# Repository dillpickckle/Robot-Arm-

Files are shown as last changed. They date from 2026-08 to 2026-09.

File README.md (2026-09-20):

5-DOF Robot Arm

A robotic arm with 400mm reach and a 250g payload, designed and built from scratch.

Robot arm
Status

Hardware: Complete — CAD, STEP files, wiring diagrams, Rough firmware, and BOM are in this repo.

Specs
5 degrees of freedom + gripper
400mm reach, 250g payload
3× NEMA 17 steppers with planetary gearboxes (base 5:1, shoulder 20:1, elbow 20:1)
3× Feetech STS3215 bus servos (wrist pitch, wrist roll, gripper)
Teensy 4.1 controller, 3× TMC2209 stepper drivers
24V power system with 12V and 5V rails
Designed in Fusion 360, printed in PETG / PA6-CF / PLA

Notes on the CAD files

No screws or bolts. Mapping every fastener would have cluttered the file without adding useful information. The BOM and assembly guide list what goes where.

No electronics. The Teensy, TMC2209s, buck converters, and other PCBs aren't modeled — I couldn't find accurate CAD for them, and the manufacturers don't publish dimensioned drawings. I'll update these once I have the parts in hand to measure.

Planetary gearbox mounting points are approximate. The manufacturer doesn't specify them. Also getting updated once I can measure them myself.

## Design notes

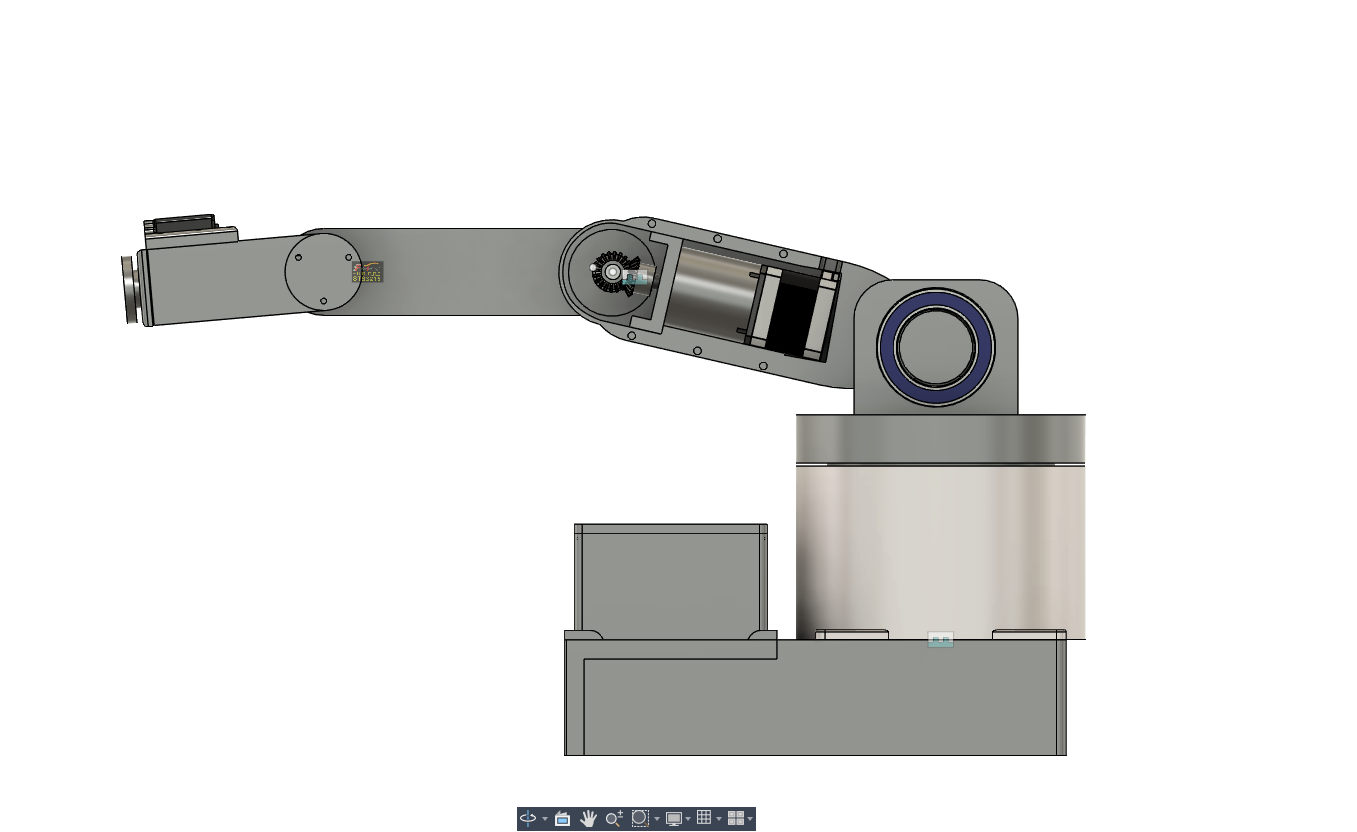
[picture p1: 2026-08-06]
Images/Screenshot 2026-08-06 085324.png

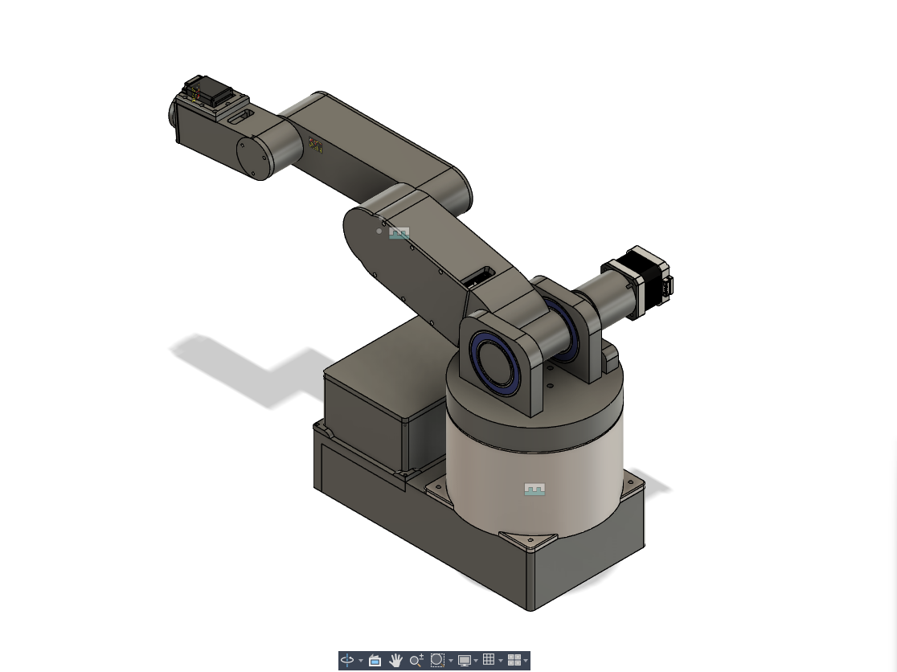
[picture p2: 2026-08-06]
Images/Screenshot 2026-08-06 085304.png

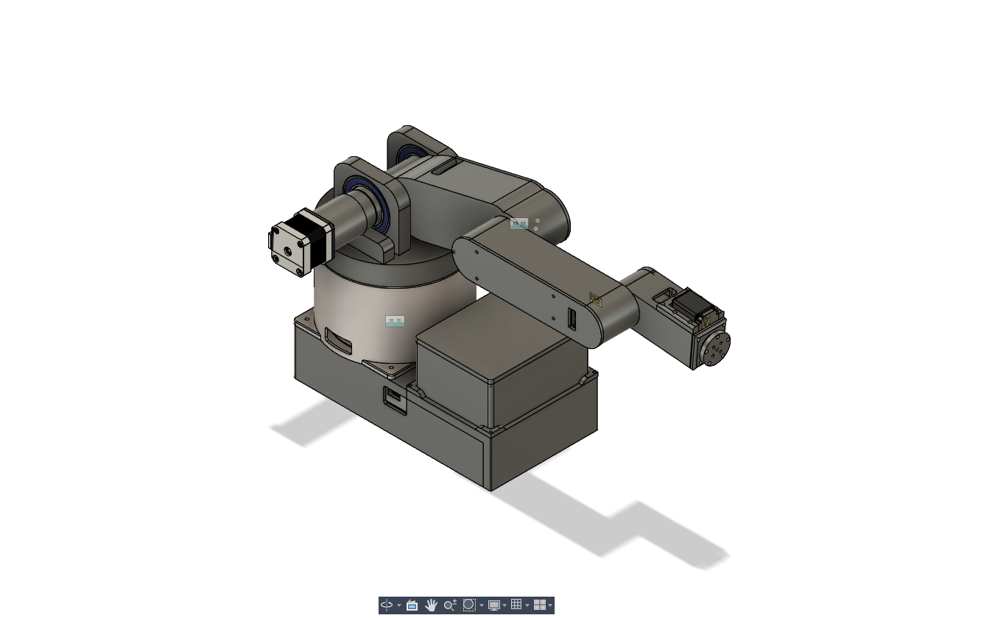
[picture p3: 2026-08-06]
Images/Screenshot 2026-08-06 085240.png

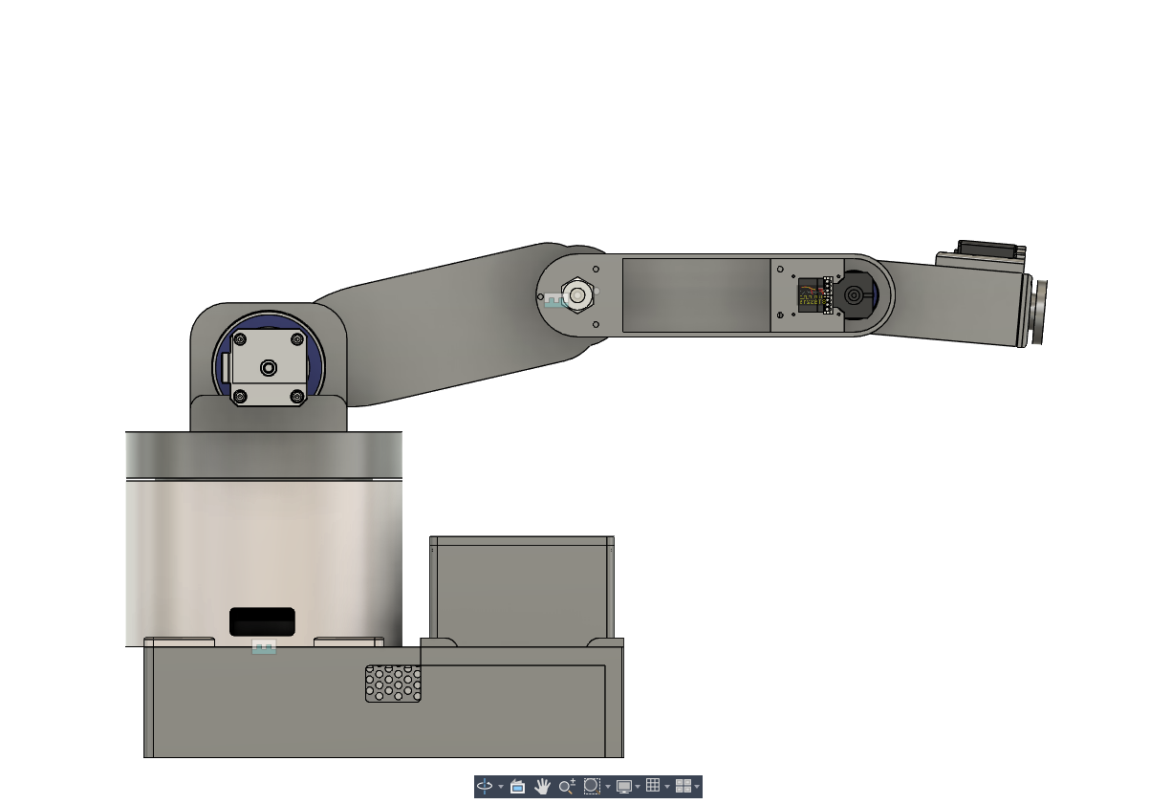
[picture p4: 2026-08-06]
Images/Screenshot 2026-08-06 085339.png

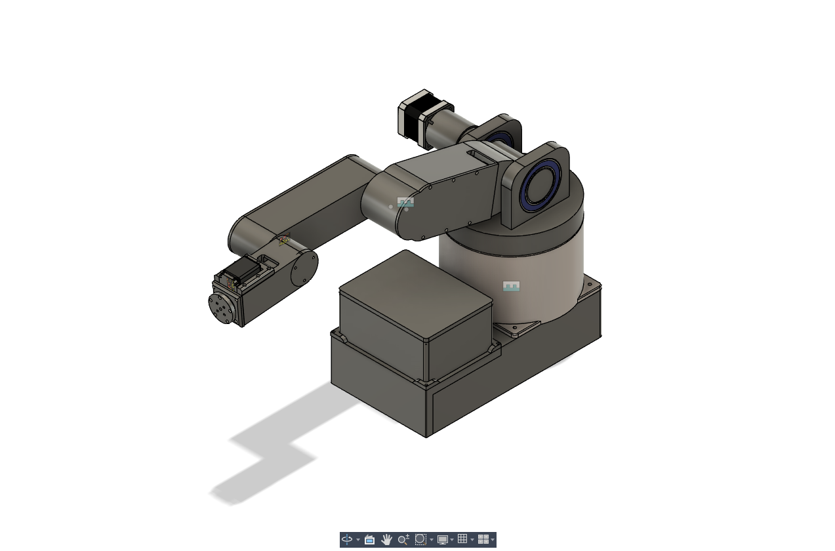
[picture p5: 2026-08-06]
Images/Screenshot 2026-08-06 085252.png

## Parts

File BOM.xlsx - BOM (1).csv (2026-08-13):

5-DOF Robot Arm - Bill of Materials
HARDWARE
Part | Qty Needed | Total Price | Source | Link
688ZZ Ball Bearing 8x16x5 | 2 | $4.73 | AliExpress | Link
6704RS Ball Bearing 20x27x4 | 2 | $1.88 | AliExpress | Link
MR52ZZ Mini Ball Bearing 2x5x2.5 | 1 | $8.59 | Amazon | Link
Thrust Bearing 90x120x4 | 1 | $8.37 | AliExpress | Link
Wheel Hex Drive Hub | 1 | $0.99 | AliExpress | Link
NEMA 17 Shaft Coupling (jaw) | 1 | $4.27 | AliExpress | Link
Spiral Bevel Gear (matched pair) | 2 | $11.85 | AliExpress | Link
Ball Bearing 6908 (40x62x12) | 2 | $9.00 | Amazon | Link
M3/M4/M5 Screw Assortment Kit | 1 | $23.00 | Amazon | Link
Heat-Set Insert Assortment Kit | 1 | $16.00 | Amazon | Link
HARDWARE SUBTOTAL |  | $88.68
MOTORS & DRIVE
Part | Qty Needed | Total Price | Source | Link
20:1 Planetary Gearbox (NEMA 17) | 1 | $26.50 | AliExpress | Link
5:1 Planetary Gearbox (NEMA 17) | 2 | $38.78 | AliExpress | Link
NEMA 17 Stepper 42N.cm | 3 | $27.27 | AliExpress | Link
STS3215 30kg Serial Bus Servo | 3 | $75.70 | AliExpress | Link
MOTORS & DRIVE SUBTOTAL |  | $168.25
ELECTRONICS
Part | Qty Needed | Total Price | Source | Link
Teensy 4.1 Microcontroller | 1 | $34.90 | Amazon | Link
TMC2209 Stepper Driver | 3 | $14.10 | AliExpress | Link
Waveshare Bus Servo Adapter (URT-1) | 1 | $17.19 | AliExpress | Link
24V PSU (200W / 8.8A) | 1 | $31.43 | AliExpress | Link
24V to 12V Buck Converter (5A) | 1 | $5.71 | AliExpress | Link
24V to 5V Buck Converter (3A) | 1 | $1.39 | AliExpress | Link
Main Power Rocker Switch | 1 | $1.61 | AliExpress | Link
Emergency Stop Button (NC) | 1 | $2.61 | AliExpress | Link
Limit Switch w/ lever | 3 | $0.99 | Aliexpress | Link
JST-XH Connector Kit + crimp tool | 1 | $30 | Amazon | Link
22 AWG Stranded Wire (multi-color) | 1 | $21 | Amazon | Link
18 AWG Wire (red/black) | 1 | $8 | Amazon | Link
Heat Shrink Tubing Assortment | 1 | $14 | Amazon | Link
Header Pin Strips (40-pin) | 1 | $8 | Amazon | Link
ELECTRONICS SUBTOTAL |  | $190.93
SHIPPING & FEES
Item |  | Total Price | Source
AliExpress Shipping |  | $30.00 | AliExpress
AliExpress Import / Customs Fees |  | $30.00 | AliExpress
Amazon Shipping |  | $0.00 | Amazon (Prime Member)
SHIPPING & FEES SUBTOTAL |  | $60.00
GRAND TOTAL |  | $507.86

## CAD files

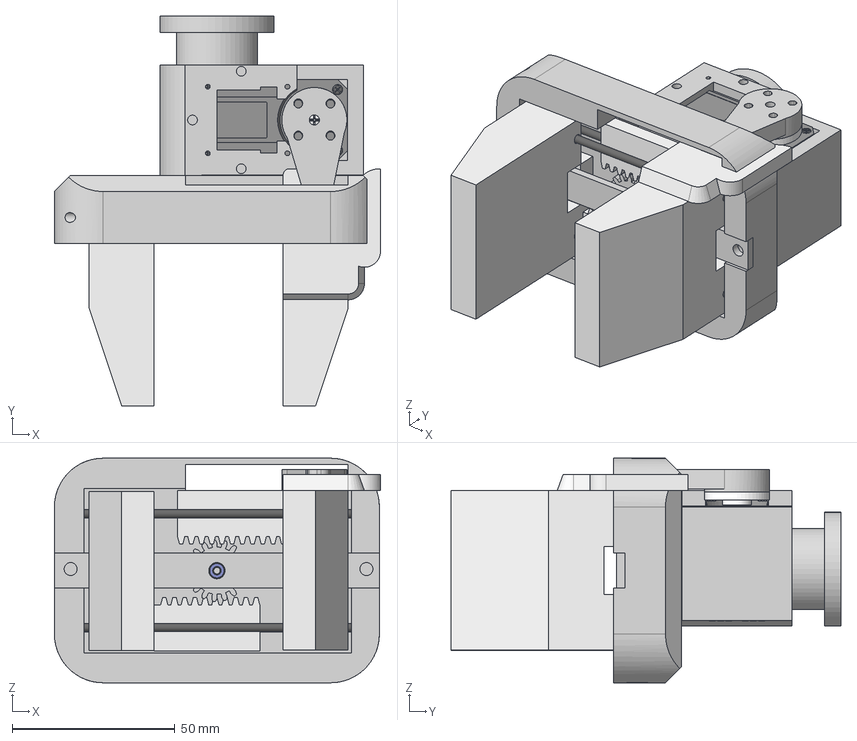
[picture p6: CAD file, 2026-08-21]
Production/Assembly Files/GripperFullAssembly.step
100.4 x 120.0 x 69.1 mm
SpurGear
vis x 2
connector F x 2
PHS JIS B 1111 - M3 x 4 - H Acier inoxydable A2 Standard
Inner ring
Covers
Outer ring
Inner ring (1)
Covers (1)
Outer ring (1)
ServoMount
Gripper2
ServoAttachment
gripper1
Main Body
BearingMount
Horizontal Rod
Horizontal ROD_1
Horizontal Rod (1)
Horizontal Rod (1) (1)

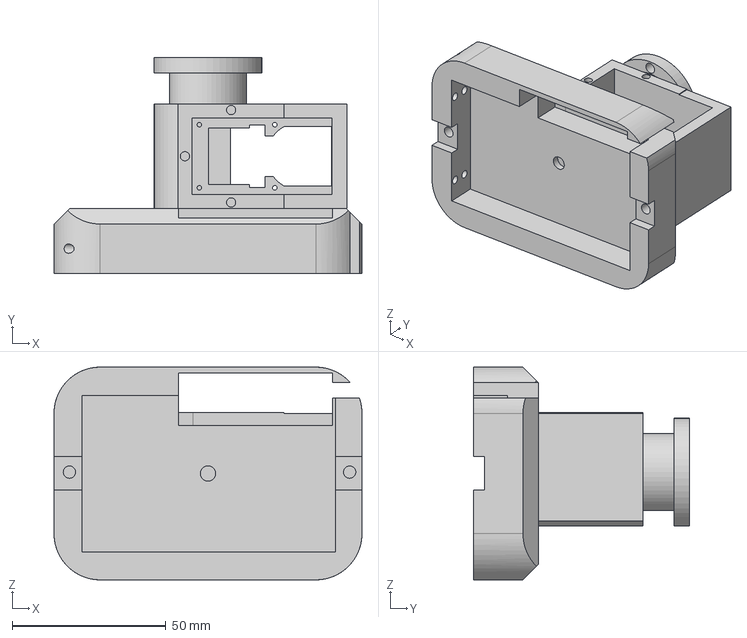
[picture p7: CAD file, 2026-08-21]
Production/Step Files/Gripper/MainBody.step
100.0 x 70.0 x 69.1 mm

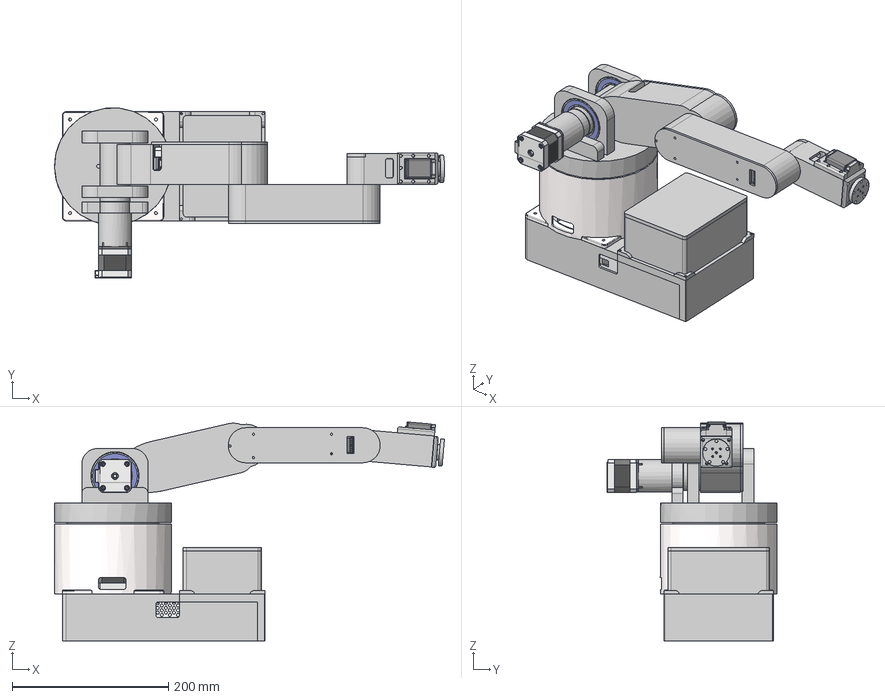
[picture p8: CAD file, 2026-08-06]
Production/Assembly Files/Fully Assembled.step
499.8 x 217.5 x 280.6 mm
Inner ring
Covers
Outer ring
rear end cap x 3
rear bearing x 3
connector x 3
shaft x 3
stator x 3
front end cap x 3
front bearing x 3
M3x10-Screw x 12
20:1 Planetary Gearbox x 3
CouplingJ1
Base
Inner ring (1)
Covers (1)
Outer ring (1)
Inner ring (2)
Covers (2)
Outer ring (2)
BevelJ32 x 2
NEMA MOUNT
ShoulderCover
vis x 4
connector F x 4
PHS JIS B 1111 - M3 x 4 - H Acier inoxydable A2 Standard x 2
ServoMountJ4
StepperMountJ5
Inner ring (3)
Covers (3)
Outer ring (3)
DriveHub
MetalBar
TopBase
Linkage1
J5BearingMount
J5Flange
Inner ring (4)
Covers (4)
Outer ring (4)
Linkage3
Linkage2
Inner ring (5)
Covers (5)
Outer ring (5)
Inner ring (6)
Covers (6)
Outer ring (6)
M3x6-Screw x 4
M3x6-Screw011
ElectronicsMainBox
SEBcover
SecondaryElectricsBox
ElectronicsMBcover
J1PlanetaryMount
J4Cover
J3/4Cover

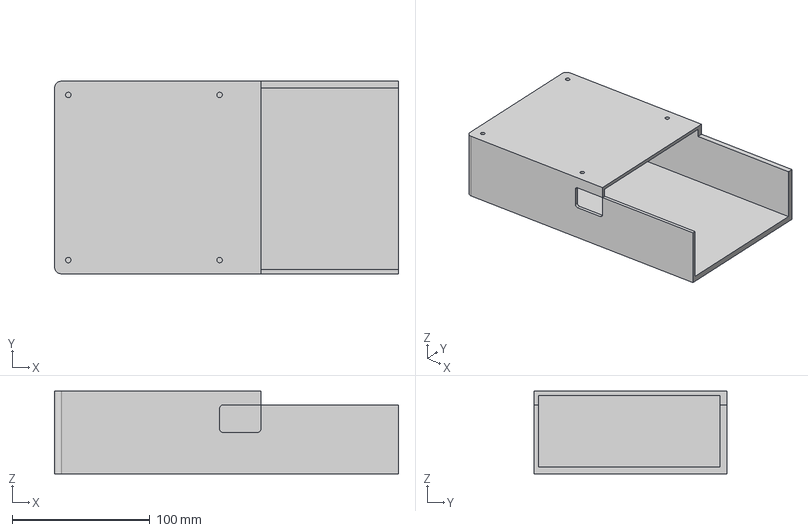
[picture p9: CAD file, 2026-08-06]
Production/Step Files/Robot Arm/ElectronicsMainBox.step
250.0 x 140.0 x 60.0 mm

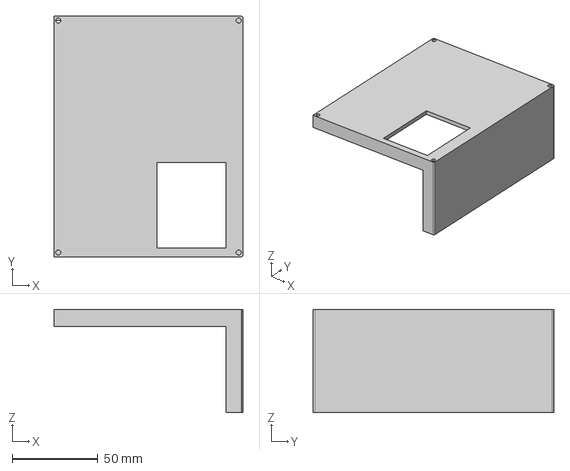
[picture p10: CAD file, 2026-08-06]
Production/Step Files/Robot Arm/ElectronicsMBcover.step
110.0 x 140.0 x 60.0 mm

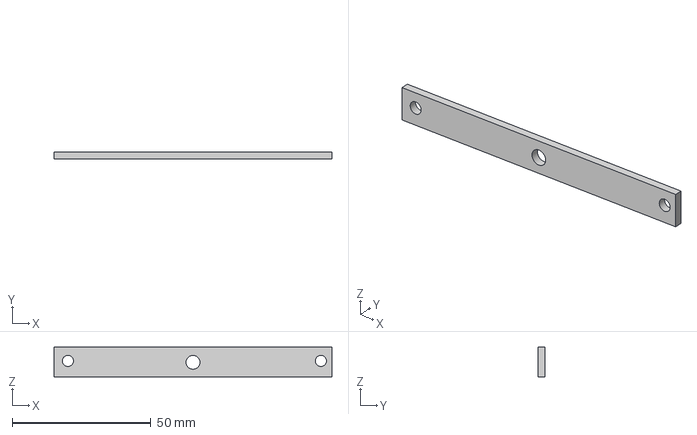
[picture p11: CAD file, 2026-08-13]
Production/Step Files/Gripper/BearingMount.step
100.0 x 2.50 x 10.8 mm

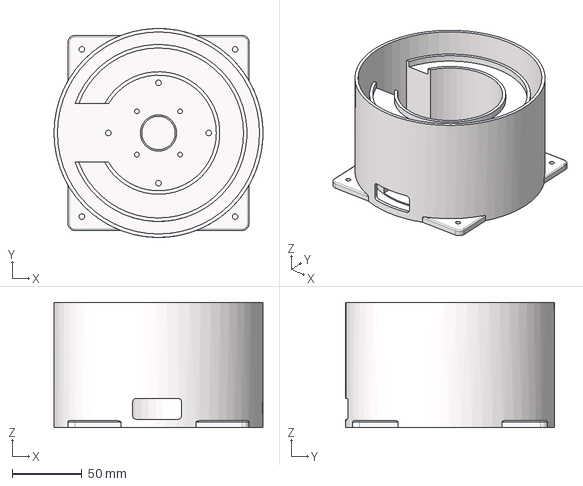
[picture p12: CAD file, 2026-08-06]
Production/Step Files/Robot Arm/Base.step
150.0 x 150.0 x 90.0 mm

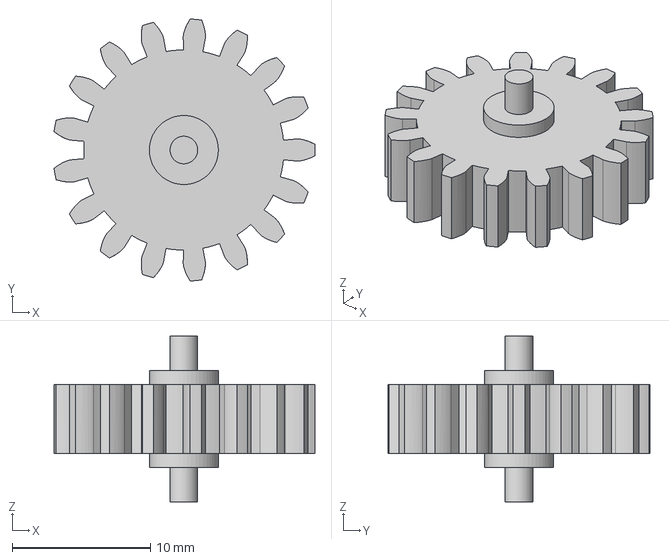
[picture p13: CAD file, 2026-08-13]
Production/Step Files/Gripper/SpurGear.step
18.9 x 19.0 x 12.0 mm

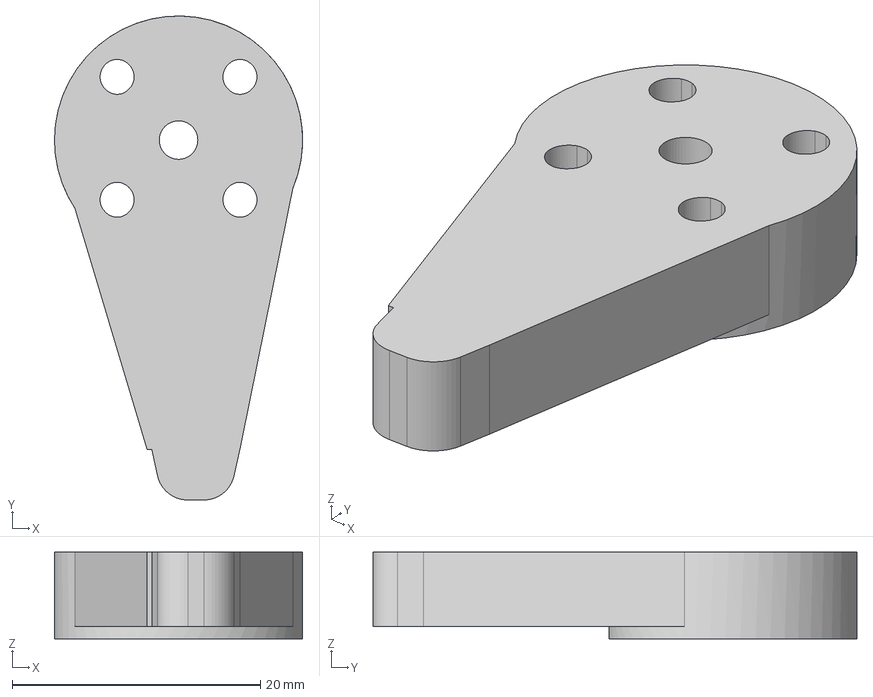
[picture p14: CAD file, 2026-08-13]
Production/Step Files/Gripper/ServoAttachment.step
20.0 x 39.0 x 7.00 mm

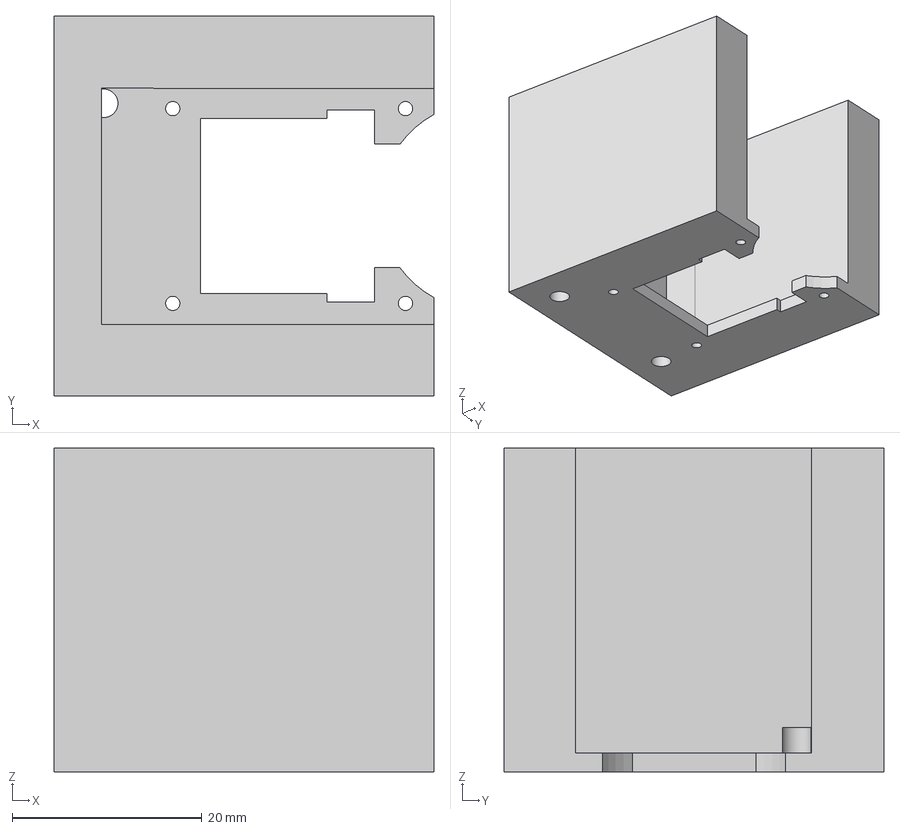
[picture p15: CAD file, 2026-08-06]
Production/Step Files/Robot Arm/ServoMountJ4.step
40.0 x 40.0 x 34.1 mm

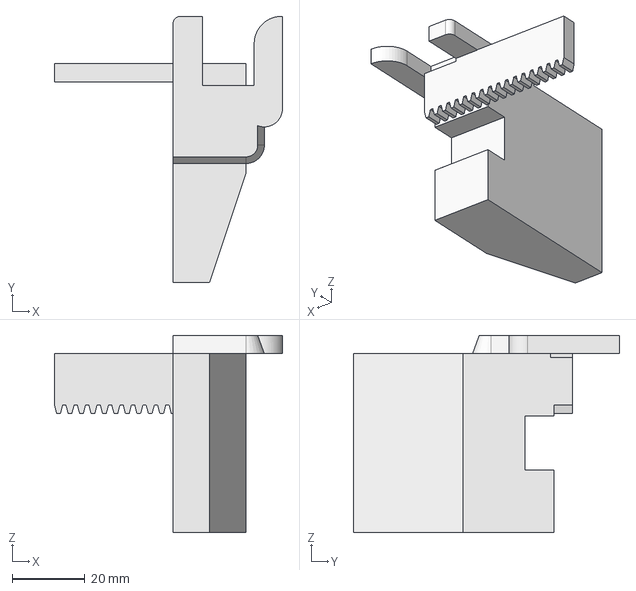
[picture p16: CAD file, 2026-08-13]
Production/Step Files/Gripper/Gripper2.step
62.5 x 73.0 x 54.0 mm

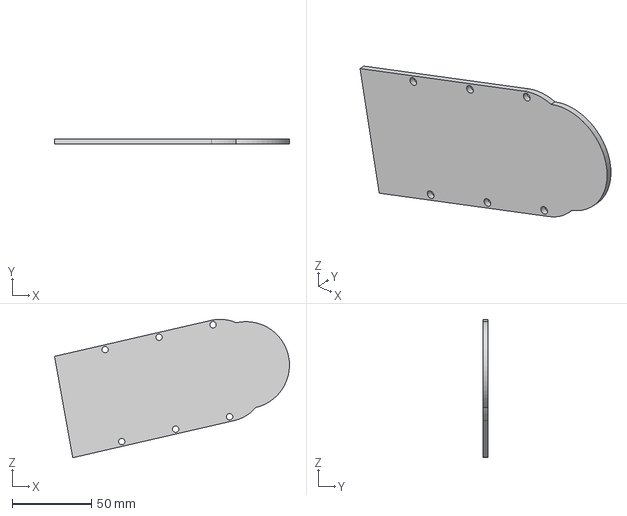
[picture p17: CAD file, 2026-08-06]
Production/Step Files/Robot Arm/ShoulderCover.step
148.5 x 3.00 x 87.4 mm

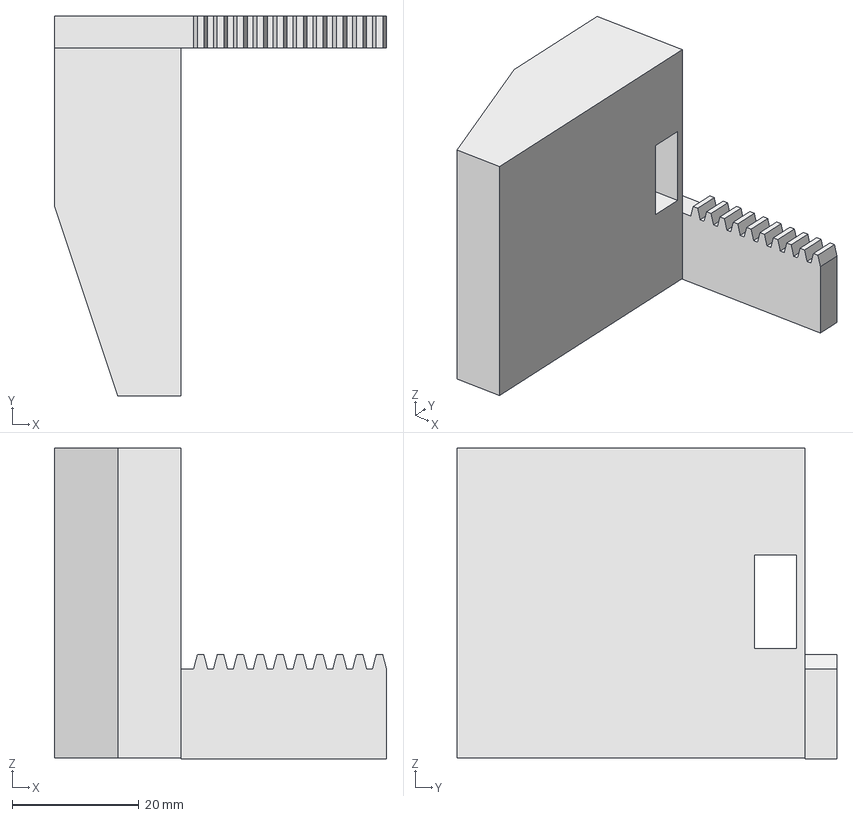
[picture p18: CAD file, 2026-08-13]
Production/Step Files/Gripper/gripper1.step
52.5 x 60.0 x 49.1 mm

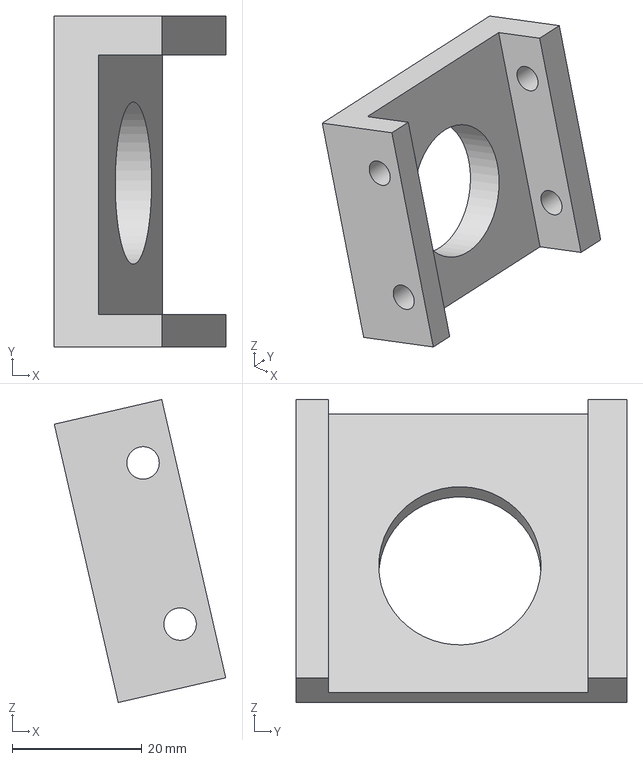
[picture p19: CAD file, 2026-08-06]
Production/Step Files/Robot Arm/J3PlanetaryMount.step
26.4 x 51.0 x 46.7 mm

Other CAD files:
Production/Step Files/Robot Arm/SecondaryElectricsBox.step
Production/Step Files/Robot Arm/J34Cover.step
Production/Step Files/Robot Arm/StepperMountJ5.step
Production/Step Files/Robot Arm/J5Flange.step
Production/Step Files/Robot Arm/J1PlanetaryMount.step
Production/Step Files/Robot Arm/J4Cover.step
Production/Step Files/Robot Arm/J5BearingMount.step
Production/Step Files/Robot Arm/Linkage1.step
Production/Step Files/Robot Arm/Linkage2.step
Production/Step Files/Robot Arm/Linkage3.step
Production/Step Files/Robot Arm/SEBcover.step
Production/Step Files/Robot Arm/TopBase.step

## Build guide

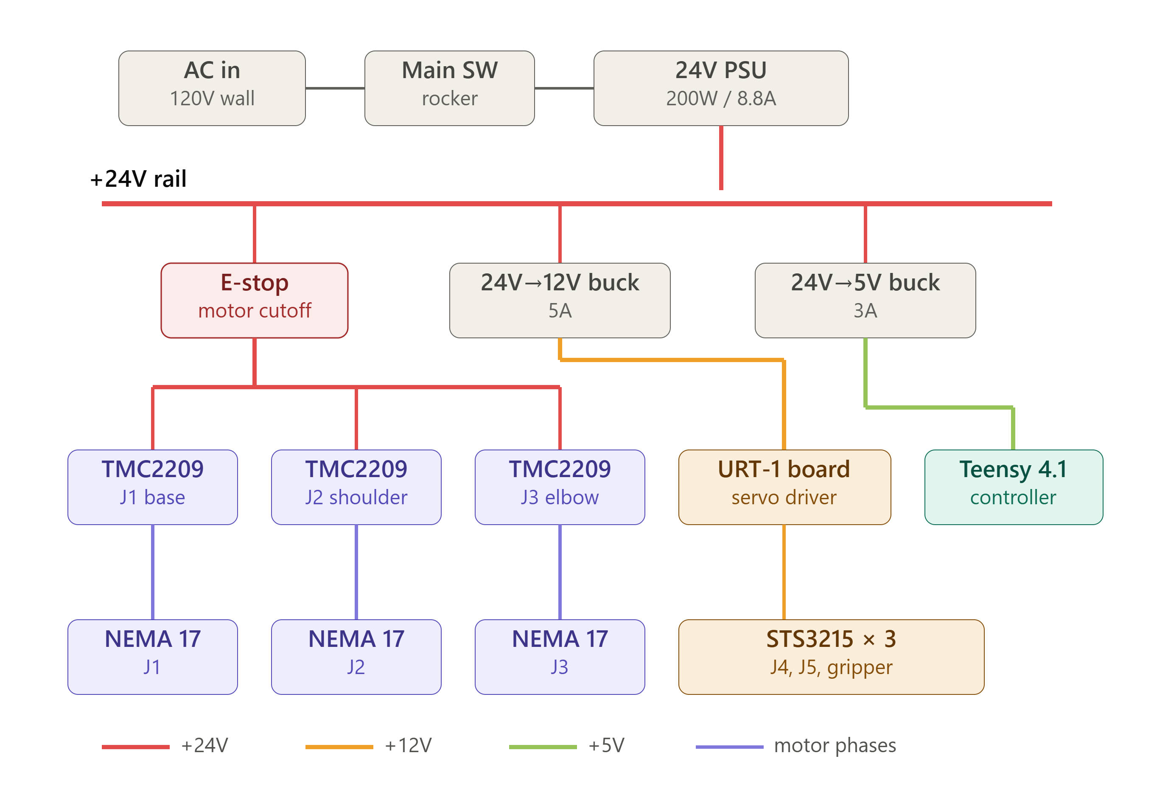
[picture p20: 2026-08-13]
Production/Wiring Diagram/wiring_power_5of_final.png

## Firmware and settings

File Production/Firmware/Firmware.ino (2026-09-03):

// --- Stepper pins (J1 base, J2 shoulder, J3 elbow) ---
const int STEP_PIN[3] = { 2, 4, 6 };
const int DIR_PIN[3]  = { 3, 5, 9 };
const int ENABLE_PIN  = 10;          // tie all three TMC2209 EN pins here

// --- Limit switch pins (one per stepper joint) ---
const int LIMIT_PIN[3] = { 20, 21, 22 };


const float MOTOR_STEPS   = 200.0;    
const float MICROSTEPS    = 16.0;     
const float GEAR_RATIO[3] = { 20.0, 5.0, 5.0 };

const float STEPS_PER_DEG[3] = {
  MOTOR_STEPS * MICROSTEPS * GEAR_RATIO[0] / 360.0f,   // J1 = 177.8 per degree
  MOTOR_STEPS * MICROSTEPS * GEAR_RATIO[1] / 360.0f,   // J2 =  44.4
  MOTOR_STEPS * MICROSTEPS * GEAR_RATIO[2] / 360.0f   // J3 =  44.4
};

// If a joint turns the wrong way, flip its sign to -1.
const int DIR_SIGN[3] = { 1, 1, 1 };

// Speed, in degrees per second at the joint. Start slow.
const float SPEED_DPS[3] = { 30.0, 20.0, 30.0 };

// --- Homing ---
// Which way each joint has to move to find its limit switch (+1 or -1).
const int   HOME_DIR[3] = { -1, -1, -1 };
// The joint angle the arm is AT when the switch clicks. MEASURE THESE.
const float HOME_DEG[3] = { -165.0, -15.0, -145.0 };

// --- Bus servos (on Serial1: pin 1 = TX to URT-1 RXD, pin 0 = RX from TXD) ---
const int SERVO_ID_J4      = 4;
const int SERVO_ID_J5      = 5;
const int SERVO_ID_GRIPPER = 6;

// STS3215: 4096 encoder counts over 360 degrees. 2048 is the middle.
// Put the raw count you measure at "zero degrees" here (use the 'raw' command).
const int SERVO_ZERO[3]  = { 2048, 2048, 2048 };   // J4, J5, gripper
const int SERVO_SIGN[3]  = { 1, 1, 1 };
const int SERVO_SPEED    = 1200;                   // counts per second

// Gripper raw counts. Measure these with the 'raw' command too.
const int GRIP_OPEN   = 2048;
const int GRIP_CLOSED = 1400;

// Don't let the arm drive itself into its own frame.
const float MIN_DEG[5] = { -170, -20, -150, -95, -160 };
const float MAX_DEG[5] = {  170, 110,   10,  95,  160 };




long  stepPos[3]    = { 0, 0, 0 };     // where we believe we are
long  stepTarget[3] = { 0, 0, 0 };     // where we are going
unsigned long lastStepUs[3] = { 0, 0, 0 };
unsigned long stepIntervalUs[3];       // microseconds between pulses
bool  motorsOn = false;

long degToSteps(int axis, float deg) { return (long)(deg * STEPS_PER_DEG[axis]); }
float stepsToDeg(int axis, long s)   { return (float)s / STEPS_PER_DEG[axis]; }

bool limitPressed(int axis) {
  // Switches are wired to GND with the pin pulled up, using the NC contact:
  // HIGH means pressed (or a broken wire, which is also a good reason to stop).
  return digitalRead(LIMIT_PIN[axis]) == HIGH;
}

void setMotors(bool on) {
  motorsOn = on;
  digitalWrite(ENABLE_PIN, on ? LOW : HIGH);   // TMC2209 EN is active LOW
  if (!on) for (int i = 0; i < 3; i++) stepTarget[i] = stepPos[i];
}

// Send exactly one pulse to one motor.
void pulse(int axis, int dir) {
  digitalWrite(DIR_PIN[axis], (dir * DIR_SIGN[axis]) > 0 ? HIGH : LOW);
  delayMicroseconds(2);                        // let DIR settle before stepping
  digitalWrite(STEP_PIN[axis], HIGH);
  delayMicroseconds(3);
  digitalWrite(STEP_PIN[axis], LOW);
  stepPos[axis] += dir;
}


void runSteppers() {
  if (!motorsOn) return;
  unsigned long now = micros();

  for (int i = 0; i < 3; i++) {
    if (stepPos[i] == stepTarget[i]) continue;
    if (now - lastStepUs[i] < stepIntervalUs[i]) continue;
    lastStepUs[i] = now;

    int dir = (stepTarget[i] > stepPos[i]) ? 1 : -1;

    // Never drive further into a switch that is already pressed.
    if (dir == HOME_DIR[i] && limitPressed(i)) {
      stepTarget[i] = stepPos[i];
      continue;
    }
    pulse(i, dir);
  }
}

bool steppersBusy() {
  for (int i = 0; i < 3; i++) if (stepPos[i] != stepTarget[i]) return true;
  return false;
}


void homeAll() {
  if (!motorsOn) { Serial.println("turn the motors on first ('on')"); return; }
  Serial.println("homing, keep clear...");

  for (int i = 0; i < 3; i++) {
    Serial.print("  J"); Serial.print(i + 1); Serial.print(" ... ");

    unsigned long start = millis();
    // Slow, deliberate approach: 4 degrees per second.
    unsigned long interval = (unsigned long)(1000000.0 / (4.0 * STEPS_PER_DEG[i]));

    while (!limitPressed(i)) {
      if (millis() - start > 20000) {            // 20 second giving-up point
        Serial.println("TIMED OUT - check the switch and HOME_DIR");
        setMotors(false);
        return;
      }
      pulse(i, HOME_DIR[i]);
      delayMicroseconds(interval);
    }

    // This is the whole point: the step count now means something real.
    stepPos[i]    = degToSteps(i, HOME_DEG[i]);
    stepTarget[i] = stepPos[i];
    Serial.println("ok");
    delay(300);
  }
  Serial.println("homed.");
}



const int SERVO_REG_GOAL_POS = 42;
const int SERVO_REG_SPEED    = 46;
const int SERVO_REG_POS      = 56;

void servoWrite(int id, int reg, const uint8_t *data, int len) {
  uint8_t packet[16];
  int n = 0;
  packet[n++] = 0xFF;
  packet[n++] = 0xFF;
  packet[n++] = id;
  packet[n++] = len + 3;         // params (reg + data) + instruction + checksum
  packet[n++] = 0x03;            // 0x03 = WRITE
  packet[n++] = reg;
  for (int i = 0; i < len; i++) packet[n++] = data[i];

  int sum = 0;
  for (int i = 2; i < n; i++) sum += packet[i];
  packet[n++] = ~sum;

  while (Serial1.available()) Serial1.read();   // drop anything stale
  Serial1.write(packet, n);
  Serial1.flush();
}

// Tell a servo to go to a raw encoder count (0..4095).
void servoGoTo(int id, int counts, int speed) {
  if (counts < 0)    counts = 0;
  if (counts > 4095) counts = 4095;
  // Registers 42..47 in one write: goal position, goal time, goal speed.
  uint8_t d[6] = {
    (uint8_t)(counts & 0xFF), (uint8_t)(counts >> 8),
    0, 0,
    (uint8_t)(speed & 0xFF),  (uint8_t)(speed >> 8)
  };
  servoWrite(id, SERVO_REG_GOAL_POS, d, 6);
  delay(2);                                     // let the bus settle
}


int servoReadPos(int id) {
  uint8_t packet[8];
  int n = 0;
  packet[n++] = 0xFF; packet[n++] = 0xFF;
  packet[n++] = id;
  packet[n++] = 4;                              // 2 params + instruction + checksum
  packet[n++] = 0x02;                           // 0x02 = READ
  packet[n++] = SERVO_REG_POS;
  packet[n++] = 2;                              // read 2 bytes
  int sum = 0;
  for (int i = 2; i < n; i++) sum += packet[i];
  packet[n++] = ~sum;

  while (Serial1.available()) Serial1.read();
  Serial1.write(packet, n);
  Serial1.flush();


  unsigned long start = millis();
  uint8_t buf[16];
  int got = 0;
  while (millis() - start < 20) {
    if (!Serial1.available()) continue;
    uint8_t b = Serial1.read();
    if (got < 2) {
      buf[got] = b;
      got = (b == 0xFF) ? got + 1 : 0;          // wait for 0xFF 0xFF
    } else {
      buf[got++] = b;
      // header(2) + id + len + error + 2 data + checksum = 8 bytes
      if (got >= 8) {
        if (buf[2] != id) { got = 0; continue; }   // that was our own echo
        return buf[5] | (buf[6] << 8);             // low byte first
      }
    }
  }
  return -1;
}

int servoDegToCounts(int slot, float deg) {
  return SERVO_ZERO[slot] + (int)(deg * SERVO_SIGN[slot] * 4096.0 / 360.0);
}

float servoCountsToDeg(int slot, int counts) {
  return (counts - SERVO_ZERO[slot]) * SERVO_SIGN[slot] * 360.0 / 4096.0;
}




float servoTargetDeg[2] = { 0, 0 };     // J4, J5

void moveJoint(int joint, float deg) {   // joint is 1..5
  int idx = joint - 1;
  if (deg < MIN_DEG[idx] || deg > MAX_DEG[idx]) {
    Serial.println("outside the joint limits");
    return;
  }
  if (!motorsOn) { Serial.println("turn the motors on first ('on')"); return; }

  if (joint <= 3) {
    stepTarget[idx] = degToSteps(idx, deg);
  } else if (joint == 4) {
    servoTargetDeg[0] = deg;
    servoGoTo(SERVO_ID_J4, servoDegToCounts(0, deg), SERVO_SPEED);
  } else {
    servoTargetDeg[1] = deg;
    servoGoTo(SERVO_ID_J5, servoDegToCounts(1, deg), SERVO_SPEED);
  }
  Serial.println("moving");
}

void printPositions() {
  Serial.print("steppers:  ");
  for (int i = 0; i < 3; i++) {
    Serial.print("J"); Serial.print(i + 1); Serial.print(" ");
    Serial.print(stepsToDeg(i, stepPos[i]), 1); Serial.print("  ");
  }
  Serial.println();

  Serial.print("servos:    ");
  int p4 = servoReadPos(SERVO_ID_J4);
  int p5 = servoReadPos(SERVO_ID_J5);
  Serial.print("J4 ");
  if (p4 < 0) Serial.print("no reply"); else Serial.print(servoCountsToDeg(0, p4), 1);
  Serial.print("  J5 ");
  if (p5 < 0) Serial.print("no reply"); else Serial.print(servoCountsToDeg(1, p5), 1);
  Serial.println();

  Serial.print("switches:  ");
  for (int i = 0; i < 3; i++) { Serial.print(limitPressed(i)); Serial.print(" "); }
  Serial.println();
}

void printRaw() {
  int ids[3] = { SERVO_ID_J4, SERVO_ID_J5, SERVO_ID_GRIPPER };
  for (int i = 0; i < 3; i++) {
    int p = servoReadPos(ids[i]);
    Serial.print("servo id "); Serial.print(ids[i]); Serial.print(" raw count: ");
    if (p < 0) Serial.println("no reply"); else Serial.println(p);
  }
}

void handleCommand(char *line) {
  // Split into a word and (maybe) a number.
  char *sp = strchr(line, ' ');
  float value = 0;
  bool hasValue = false;
  if (sp) { *sp = 0; value = atof(sp + 1); hasValue = true; }

  if (!strcmp(line, "on"))        { setMotors(true);  Serial.println("motors on"); }
  else if (!strcmp(line, "off"))  { setMotors(false); Serial.println("motors off"); }
  else if (!strcmp(line, "home")) { homeAll(); }
  else if (!strcmp(line, "pos"))  { printPositions(); }
  else if (!strcmp(line, "raw"))  { printRaw(); }
  else if (!strcmp(line, "grip")) {
    if (!hasValue) { Serial.println("usage: grip 0-100"); return; }
    if (value < 0) value = 0;
    if (value > 100) value = 100;
    int counts = GRIP_CLOSED + (int)((GRIP_OPEN - GRIP_CLOSED) * value / 100.0);
    servoGoTo(SERVO_ID_GRIPPER, counts, SERVO_SPEED);
    Serial.println("gripper moving");
  }
  else if (line[0] == 'j' && line[1] >= '1' && line[1] <= '5' && line[2] == 0) {
    if (!hasValue) { Serial.println("usage: j1 45"); return; }
    moveJoint(line[1] - '0', value);
  }
  else {
    Serial.println("commands: on  off  home  j1..j5 <deg>  grip <0-100>  pos  raw");
  }
}

// Collect characters until Enter, then act on the line.
char cmdBuf[40];
int  cmdLen = 0;

void readSerial() {
  while (Serial.available()) {
    char c = Serial.read();
    if (c == '\r') continue;
    if (c == '\n') {
      cmdBuf[cmdLen] = 0;
      if (cmdLen > 0) handleCommand(cmdBuf);
      cmdLen = 0;
    } else if (cmdLen < (int)sizeof(cmdBuf) - 1) {
      cmdBuf[cmdLen++] = c;
    }
  }
}



void setup() {
  for (int i = 0; i < 3; i++) {
    pinMode(STEP_PIN[i], OUTPUT);
    pinMode(DIR_PIN[i],  OUTPUT);
    pinMode(LIMIT_PIN[i], INPUT_PULLUP);
    digitalWrite(STEP_PIN[i], LOW);

    // Work out the delay between step pulses from the speed setting.
    stepIntervalUs[i] = (unsigned long)(1000000.0 / (SPEED_DPS[i] * STEPS_PER_DEG[i]));
  }

  pinMode(ENABLE_PIN, OUTPUT);
  setMotors(false);                     // always boot with the motors off

  Serial.begin(115200);
  Serial1.begin(1000000);               // the servo bus, via the URT-1 adapter
  delay(500);

  Serial.println();
  Serial.println("5-DOF arm - basic firmware");
  Serial.println("motors are off, the arm is limp. nothing will move yet.");
  Serial.println("commands: on  off  home  j1..j5 <deg>  grip <0-100>  pos  raw");
  Serial.println();
}

void loop() {
  runSteppers();     // must be called constantly, this is what moves the motors
  readSerial();
}
